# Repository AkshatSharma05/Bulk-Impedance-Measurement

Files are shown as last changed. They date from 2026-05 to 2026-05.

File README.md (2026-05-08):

# Bulk Impedance Measurement Tool
## Overview

This repository contains the PCB design for a bulk impedance measurement tool built around an ESP32, an AD9833 DDS signal generator, and the internal ADC for measurement.

The system generates a sinusoidal excitation signal, conditions and buffers it, and applies it to a voltage divider formed by a known resistor (R_known) and an external unknown impedance (Z_unknown). The ESP32 measures the input and output voltages using its ADC and computes the unknown impedance using:

```Z_unknown = R_known × (Vout / (Vin − Vout))```

<img width="704" height="811" alt="Screenshot from 2026-05-09 03-07-40" src="https://github.com/user-attachments/assets/5638d713-5db1-44f7-b73f-7a7bd33e2604" />

## Notes
- The design is intended for low-voltage impedance measurement experiments and prototyping.
- Best sensitivity is achieved when R_known ≈ Z_unknown.
- All measurements are performed using AC excitation.
- The DIP Switches provided can be used to change the value of R_known -> 1K, 10K, 100K.

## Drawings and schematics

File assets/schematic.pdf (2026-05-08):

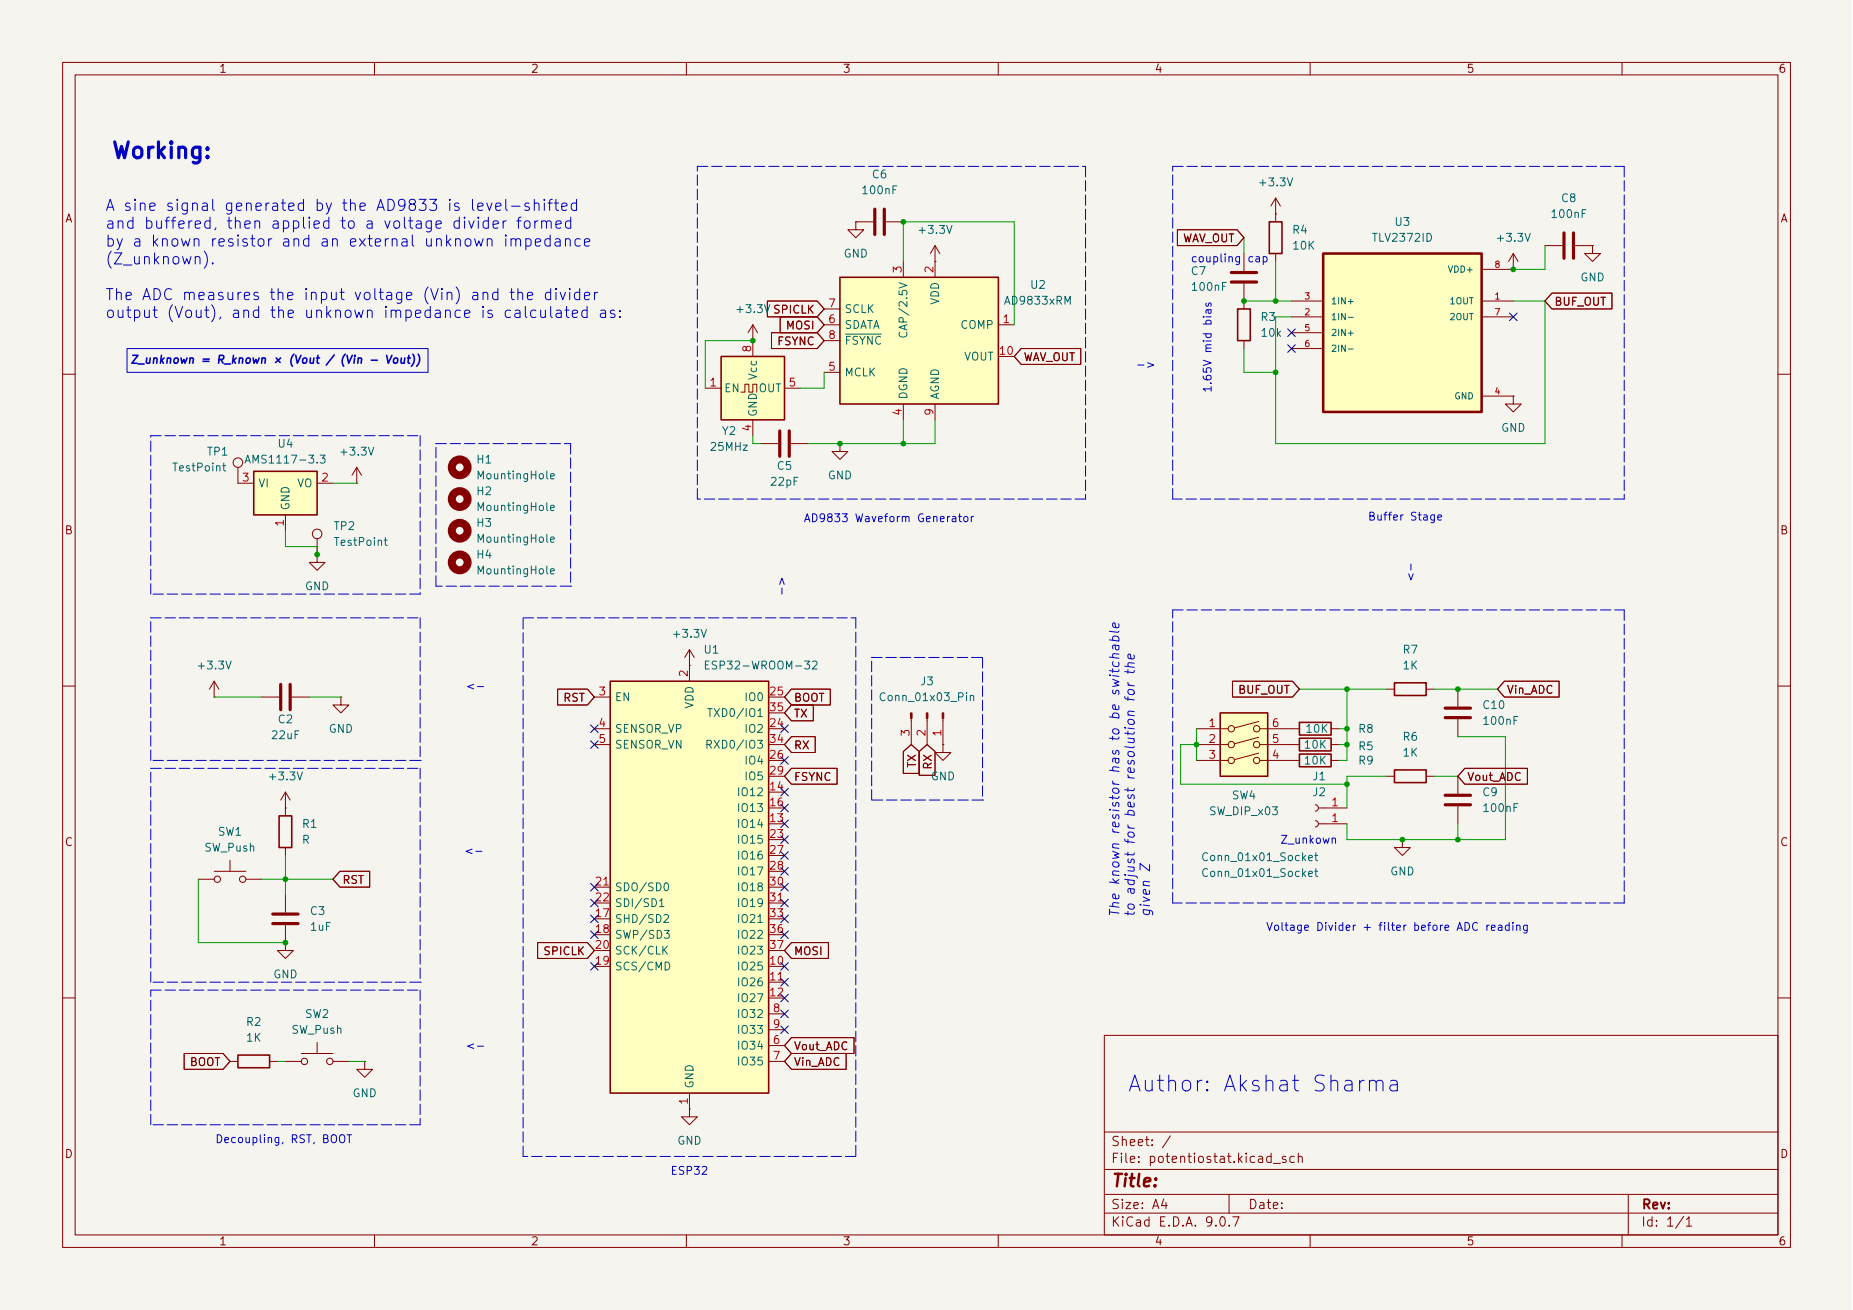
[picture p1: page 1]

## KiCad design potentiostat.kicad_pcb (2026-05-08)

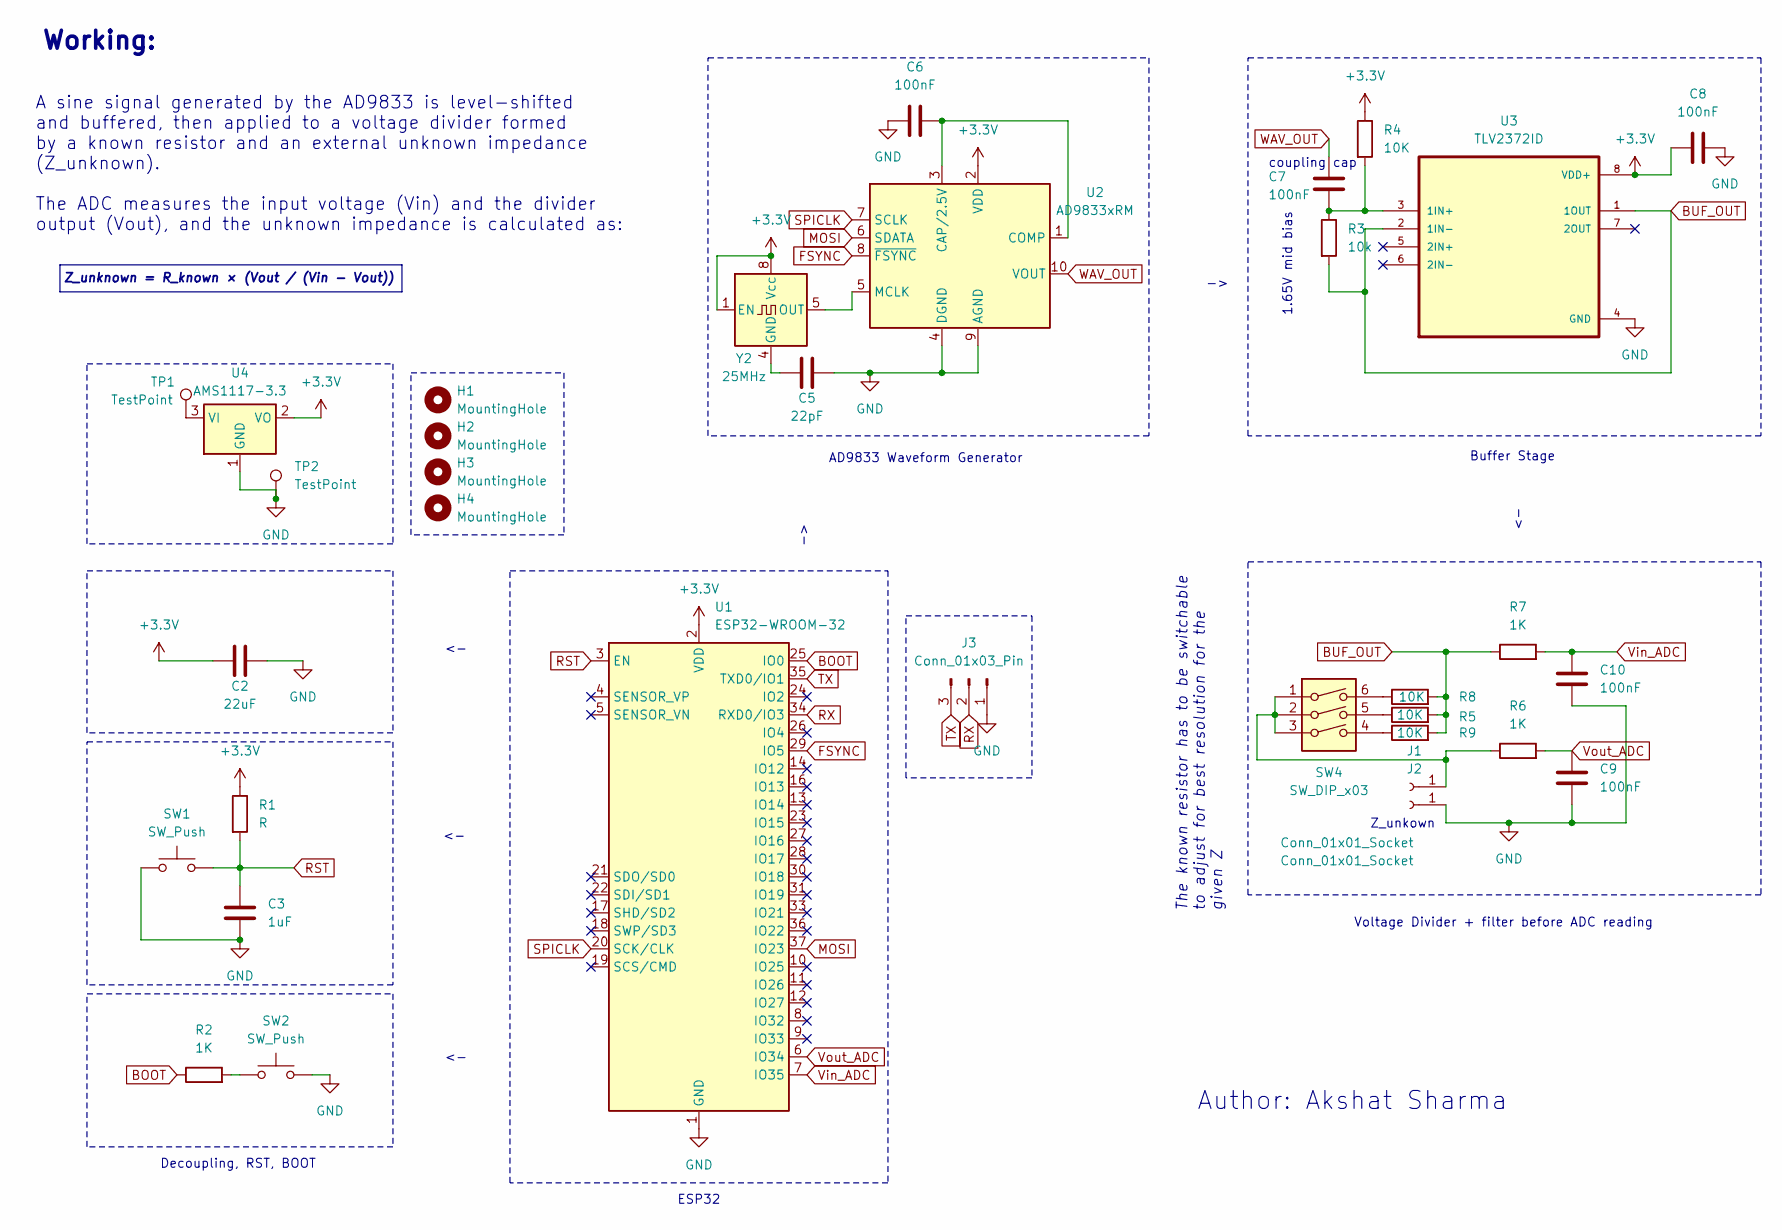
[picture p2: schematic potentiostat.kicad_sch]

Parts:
C2: 22uF; C_0201_0603Metric
C3: 1uF; C_0201_0603Metric
C5: 22pF; C_0201_0603Metric
C6, C7, C8, C9, C10: 100nF; C_0201_0603Metric
H1, H2, H3, H4: MountingHole; MountingHole_2.5mm
J1, J2: Conn_01x01_Socket; BNC_TEConnectivity_1478204_Vertical
J3: Conn_01x03_Pin; PinHeader_1x03_P2.54mm_Horizontal
R1: R; R_0603_1608Metric
R2, R6, R7: 1K; R_0603_1608Metric
R3: 10k; R_0603_1608Metric
R4, R5, R8, R9: 10K; R_0603_1608Metric
SW1, SW2: SW_Push; SW_Tactile_SPST_NO_Straight_CK_PTS636Sx25SMTRLFS
SW4: SW_DIP_x03; SW_DIP_SPSTx03_Slide_KingTek_DSHP03TJ_W5.25mm_P1.27mm_JPin
TP1, TP2: TestPoint; TestPoint_Pad_2.5x2.5mm
U1: ESP32-WROOM-32
U2: AD9833xRM; MSOP-10_3x3mm_P0.5mm
U3: TLV2372ID; SOIC127P599X175-8N; DigiKey_Part_Number TLV2372ID-ND
U4: AMS1117-3.3; SOT-223-3_TabPin2
Y2: 25MHz; Oscillator_DIP-8

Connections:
+3.3V: C2.1, C8.1, R1.1, R4.1, U1.2 (VDD), U2.2 (VDD), U3.8 (VDD+), U4.2 (VO), Y2.1 (EN), Y2.8 (Vcc)
BOOT: R2.1, U1.25 (IO0)
BUF_OUT: R3.2, R5.2, R7.1, R8.2, R9.2, U3.1 (1OUT), U3.2 (1IN-)
FSYNC: U1.29 (IO5), U2.8 (~FSYNC)
GND: C2.2, C3.2, C5.2, C6.1, C8.2, C9.1, C10.2, J2.1, J3.1, SW1.1, SW2.2, TP2.1, U1.1 (GND), U1.15 (GND), U1.38 (GND), U1.39 (GND), U2.4 (DGND), U2.9 (AGND), U3.4 (GND), U4.1 (GND); also elsewhere on the board
MOSI: U1.37 (IO23), U2.6 (SDATA)
unnamed: J1.1, R6.1, SW4.1, SW4.2, SW4.3
unnamed: R2.2, SW2.1
unnamed: R5.1, SW4.5
unnamed: R8.1, SW4.6
unnamed: R9.1, SW4.4
unnamed: C6.2, U2.1 (COMP), U2.3 (CAP/2.5V)
unnamed: U2.5 (MCLK), Y2.5 (OUT)
unnamed: C7.2, R3.1, R4.2, U3.3 (1IN+)
unnamed 14: TP1.1, U4.3 (VI); also elsewhere on the board
unnamed: C5.1, Y2.4 (GND)
RST: C3.1, R1.2, SW1.2, U1.3 (EN)
RX: J3.2, U1.34 (RXD0/IO3)
SPICLK: U1.20 (SCK/CLK), U2.7 (SCLK)
TX: J3.3, U1.35 (TXD0/IO1)
Vin_ADC: C10.1, R7.2, U1.7 (IO35)
Vout_ADC: C9.2, R6.2, U1.6 (IO34)
WAV_OUT: C7.1, U2.10 (VOUT)

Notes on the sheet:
1.65V mid bias
coupling cap
Voltage Divider + filter before ADC reading
Z_unkown
AD9833 Waveform Generator
Z_unknown = R_known × (Vout / (Vin − Vout))
Author: Akshat Sharma
ESP32
The known resistor has to be switchable to adjust for best resolution for the given Z
Decoupling, RST, BOOT
Working:
Buffer Stage
A sine signal generated by the AD9833 is level-shifted and buffered, then applied to a voltage divider formed by a known resistor and an external unknown impedance (Z_unknown). The ADC measures the input voltage (Vin) and the divider output (Vout), and the unknown impedance is calculated as:

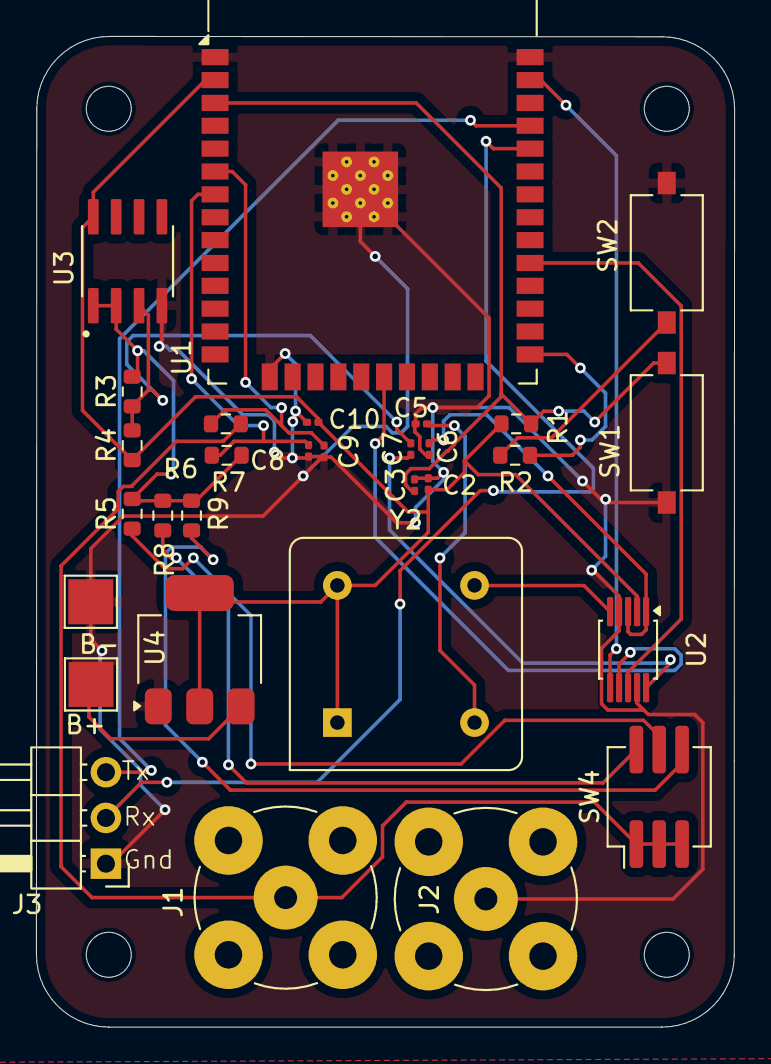
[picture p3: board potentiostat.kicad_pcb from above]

Board: 2 copper layers, 38.8 x 55.0 mm, 34 parts (0 on the bottom side), 23 nets.

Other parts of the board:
B+: TestPoint; TestPoint_Pad_2.5x2.5mm
B-: TestPoint; TestPoint_Pad_2.5x2.5mm

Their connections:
GND: B-.1; also elsewhere on the board
unnamed 14: B+.1; also elsewhere on the board

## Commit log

2026-05-08 completed pcb
    [potentiostat.kicad_pcb, potentiostat.kicad_sch]
2026-05-08 dip switch added
    [potentiostat.kicad_pcb, potentiostat.kicad_sch]
2026-05-08 debugging pins
    [potentiostat.kicad_pcb, potentiostat.kicad_sch]
